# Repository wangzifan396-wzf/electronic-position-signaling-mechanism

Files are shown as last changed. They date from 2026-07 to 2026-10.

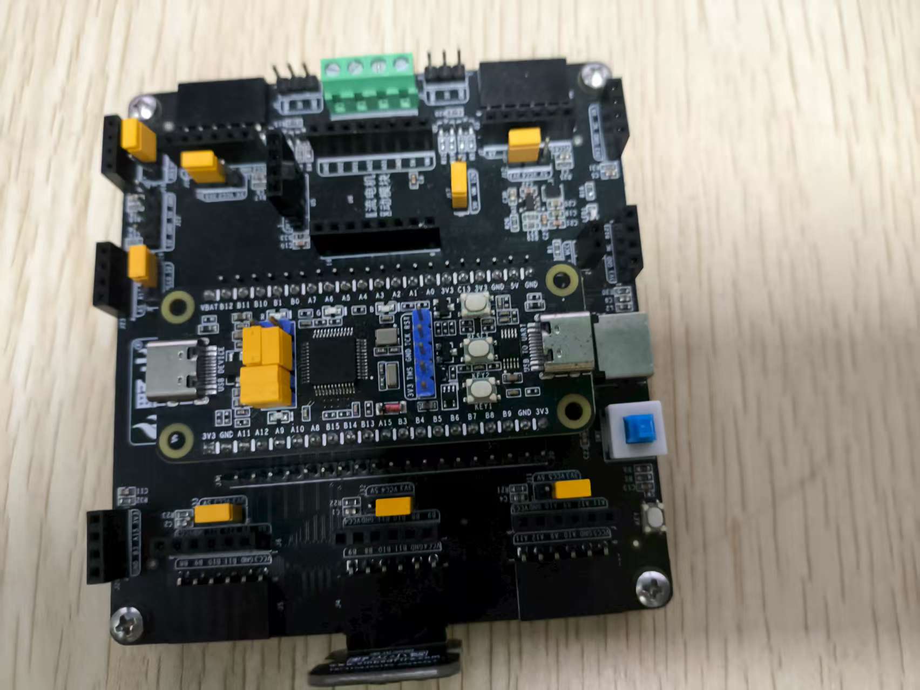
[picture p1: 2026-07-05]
[33]VL53L0X激光测距实验-3改/Doc/硬件接线图（含面包板+扩展板）/拓展板.jpg

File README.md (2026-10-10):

# Supporting research materials: electronic position-signaling mechanism

[中文说明](README.zh-CN.md) · [Final firmware release](https://github.com/wangzifan396-wzf/electronic-position-signaling-mechanism/releases/tag/v1.0.0) · [Manuscript correspondence and availability](docs/CODE_AVAILABILITY.md)

This repository provides firmware, mechanical models and engineering drawings accompanying a ground-based prototype study of an electronic position-signaling mechanism for coring. The implementation combines SDM18 distance sensing, stepper-driven inner-tube motion and ESP8266 TCP communication for position signaling, core-full and suspected-jamming alarms, and retrieval control.

**The main experiments reported in the manuscript used the single-attempt implementation (`wifi-once`).** Both author-designated final implementations are retained. Experimental procedures, actual parameter settings and reported results are documented in the manuscript; use its settings when reproducing a reported test.

## Materials

| Material | Entry point |
|---|---|
| Main experimental implementation | [firmware/wifi-once](firmware/wifi-once/) |
| Final implementation with failed-connection retries | [firmware/wifi-retry](firmware/wifi-retry/) |
| Mechanical models and original drawings | [Mechanical directory](%E6%9C%BA%E6%A2%B0/) · [Five drawing groups and thesis figures](%E6%9C%BA%E6%A2%B0/%E5%B7%A5%E7%A8%8B%E5%9B%BE/) |
| Original development projects | [Index of all 24 original directories](docs/PROJECT_FILES.md) |
| Citation and manuscript wording | [Code and design availability](docs/CODE_AVAILABILITY.md) |

The original directories and 16 mechanical models are retained in `main`. The drawing directory contains the original PDF/PNG exports, SolidWorks drawings and four engineering figures extracted unchanged from the thesis. The two final firmware implementations remain under `firmware/`.

## Firmware variants and experimental parameters

“Once” and “retry” refer to **WiFi connection attempts**. `wifi-once` attempts connection during startup; `wifi-retry` additionally retries at a nominal 30 s interval while the connection flag remains zero. These names do not indicate the number of coring cycles. [Implementation notes](docs/KNOWN_LIMITATIONS.md) explain the connection behavior in detail.

The two retained source snapshots contain initialization settings from different stages of the experimental work. The following values are **source defaults**; parameters for a reported experiment follow the corresponding manuscript record.

| Final source snapshot | Original final folder | Landed default | Upper/ground default | Core-full default |
|---|---|---:|---:|---:|
| [wifi-once](firmware/wifi-once/) | `SDM18测距机构-3wifi修改版（一次）` | 360 mm | 700 mm | 70 mm |
| [wifi-retry](firmware/wifi-retry/) | `SDM18测距机构-3wifi修改版（多次 ）` | 400 mm | 800 mm | 100 mm |

Landed, upper/ground, core-full and suspected-jamming thresholds, together with the motor software-delay setting, can be adjusted through TCP commands. `GET_PARAMS` returns the current settings. Changes are held in RAM; an MCU restart restores the source defaults. Timing and buffer settings are defined in the source and require recompilation to change. See the [command ranges and interface definitions](docs/PROTOCOL.md).

## Using the materials

1. For the main manuscript experiments, start with `firmware/wifi-once/` and configure the parameters reported for the relevant test.
2. Create the local network configuration from `Core/Inc/wifi_config.example.h`. Follow the [build and configuration guide](docs/BUILD.md) for the saved Keil project and board settings.
3. Use the drawing index to view full-sheet PDFs and locate the corresponding native CAD files. The PDFs can be read independently; opening native files may require locating their original model references.

[Source and build checks](docs/VALIDATION.md) document the checks performed for the published materials. [Implementation notes](docs/KNOWN_LIMITATIONS.md) retain the details needed to interpret and extend the original firmware.

## Cite and identify the materials

The fixed [v1.0.0 release](https://github.com/wangzifan396-wzf/electronic-position-signaling-mechanism/releases/tag/v1.0.0) identifies the two final firmware snapshots. Models and drawings are also available in the repository; the [availability guide](docs/CODE_AVAILABILITY.md) provides a fixed drawing snapshot and short Chinese/English manuscript statements. The existing v1.0.0 archives contain the firmware, while the engineering drawings added on 2026-10-10 are available separately in `main`.

`CITATION.cff` supplies the versioned software citation. The author's original code, self-drawn material and documentation use the [MIT license](LICENSE); third-party components retain their own licenses and notices. See [Third-party notices](THIRD_PARTY_NOTICES.md).

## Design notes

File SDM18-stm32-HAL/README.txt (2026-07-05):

/**********************************************************
***	Emm_V5.0步进闭环控制例程
***	控制例程：STM32_脉冲控制_while循环发送脉冲
***	编写作者：ZHANGDATOU
***	技术支持：张大头闭环伺服
***	淘宝店铺：https://zhangdatou.taobao.com
***	CSDN博客：http s://blog.csdn.net/zhangdatou666
***	qq交流群：262438510
**********************************************************/

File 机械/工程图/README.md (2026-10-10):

# Thesis engineering drawings / 论文工程图

[Mechanical directory / 返回机械目录](../) · [Repository guide / 仓库说明](../../README.md)

Added on **2026-10-10** from the author's original drawing set. The outer tube, rack, gear and inner-tube drawings correspond to the engineering views in thesis Figures 3-1 to 3-4. The simulated-core drawing is included from the same source set. The drawings and exported files are retained as supplied, without redrawing or changing dimensions.

2026-10-10新增作者原成套工程图。外管、齿条、齿轮、内管与论文终稿图3-1至图3-4中的工程视图对应，模拟岩芯为同套资料中的第五组图纸。原图及导出文件原样保留，没有重绘或改写尺寸。

## Five drawing groups / 五组工程图

PDF files contain the full original drawing sheet and title block. Use PDF to read dimensions, PNG for a quick preview, and SLDDRW to edit in SolidWorks.

PDF保留完整原图纸及题栏，建议用PDF查看尺寸、PNG快速浏览，需编辑时使用SolidWorks原工程图。

| Component / 部件 | PDF drawing / 完整图纸 | PNG preview / 预览 | SolidWorks original / 原工程图 | Thesis figure / 终稿图号 |
|---|---|---|---|---|
| Outer tube / 外管 | [PDF](PDF/90%E5%A4%96%E7%AE%A1.pdf) | [PNG](PNG/90%E5%A4%96%E7%AE%A1_01.png) | [SLDDRW](SolidWorks/90%E5%A4%96%E7%AE%A1.SLDDRW) | 图3-1 |
| Inner tube / 内管 | [PDF](PDF/65%E5%86%85%E7%AE%A1.pdf) | [PNG](PNG/65%E5%86%85%E7%AE%A1_01.png) | [SLDDRW](SolidWorks/65%E5%86%85%E7%AE%A1.SLDDRW) | 图3-4 |
| Rack / 齿条 | [PDF](PDF/%E9%BD%BF%E6%9D%A1.pdf) | [PNG](PNG/%E9%BD%BF%E6%9D%A1_01.png) | [SLDDRW](SolidWorks/%E9%BD%BF%E6%9D%A1.SLDDRW) | 图3-2 |
| Gear / 齿轮 | [PDF](PDF/%E9%BD%BF%E8%BD%AE.pdf) | [PNG](PNG/%E9%BD%BF%E8%BD%AE_01.png) | [SLDDRW](SolidWorks/%E9%BD%BF%E8%BD%AE.SLDDRW) | 图3-3 |
| Simulated core / 模拟岩芯 | [PDF](PDF/%E6%A8%A1%E6%8B%9F%E5%B2%A9%E8%8A%AF.pdf) | [PNG](PNG/%E6%A8%A1%E6%8B%9F%E5%B2%A9%E8%8A%AF_01.png) | [SLDDRW](SolidWorks/%E6%A8%A1%E6%8B%9F%E5%B2%A9%E8%8A%AF.SLDDRW) | — |

`SolidWorks/` contains **six native CAD files: five SLDDRW drawings and one SLDPRT rack model**. The same-source [rack model](SolidWorks/%E9%BD%BF%E6%9D%A1.SLDPRT) is kept next to its drawing. It differs from the original rack model in the parent mechanical directory and does not replace that file.

`SolidWorks/`共有**6个CAD原文件：5个SLDDRW工程图、1个SLDPRT齿条模型**。同源齿条模型与其工程图一同保存，与上级机械目录中的原齿条模型分别保留。

## Original thesis images / 论文原图

These four PNG files were extracted as the exact embedded image bytes from the thesis. They preserve the author's original combined engineering views and model screenshots. They are distinct from the full-sheet PNG exports above.

以下4幅PNG为论文中嵌入图片的原字节提取，保留作者原有的设计视图与模型截图组合；它们与上面的完整工程图PNG导出文件分别保存。

| Thesis figure / 论文图号 | Original image / 原图 | Corresponding drawing group / 对应工程图组 |
|---|---|---|
| 图3-1 | [论文原图 / Original image](%E8%AE%BA%E6%96%87%E5%8E%9F%E5%9B%BE/%E5%9B%BE3-1_%E5%A4%96%E7%AE%A1.png) | 90外管 |
| 图3-4 | [论文原图 / Original image](%E8%AE%BA%E6%96%87%E5%8E%9F%E5%9B%BE/%E5%9B%BE3-4_%E5%86%85%E7%AE%A1%E6%80%BB%E6%88%90.png) | 65内管 |
| 图3-2 | [论文原图 / Original image](%E8%AE%BA%E6%96%87%E5%8E%9F%E5%9B%BE/%E5%9B%BE3-2_%E9%BD%BF%E6%9D%A1.png) | 齿条 |
| 图3-3 | [论文原图 / Original image](%E8%AE%BA%E6%96%87%E5%8E%9F%E5%9B%BE/%E5%9B%BE3-3_%E9%BD%BF%E8%BD%AE.png) | 齿轮 |

## File integrity and opening CAD files / 文件校验与CAD打开说明

[DRAWING_MANIFEST.json](DRAWING_MANIFEST.json) records the relative path, size and SHA-256 of each of the **20 original files**: five PDFs, five PNG previews, five SLDDRW drawings, one SLDPRT rack model and four thesis images. The manifest and this guide are additional documentation, not part of that 20-file count.

清单记录20个原文件的路径、大小及SHA-256：5个PDF、5个PNG、5个SLDDRW、1个SLDPRT和4幅论文原图。校验清单与本说明属于另增文档，不计入20个原文件。

The native CAD files retain their original references. Their external dependencies have not been resolved or rebuilt in SolidWorks during this update. When opening a drawing, locate the referenced part or assembly if SolidWorks requests it; the PDFs can be viewed independently. Publication of these files is not a new manufacturing review or a validation of rebuilt CAD dependencies.

CAD原件保留原引用，本次未在SolidWorks中重新解析依赖或重建。打开图纸时，如软件提示缺少零件或装配体，请定位对应模型；PDF不依赖CAD模型即可查看。本次公开原图不代表新增制造校审或已验证CAD依赖完整。

The author's self-drawn material is covered by the repository's [MIT license](../../LICENSE). Third-party supplied models and vendor material retain their original terms; see [Third-party notices](../../THIRD_PARTY_NOTICES.md).

作者自绘资料采用根目录MIT许可；第三方随附模型与厂商资料继续遵循原许可，详见上述第三方说明。

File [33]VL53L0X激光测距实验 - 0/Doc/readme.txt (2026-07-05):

/*********************************************************************************************/
/*【*】程序简介

- 工程名称        ：VL53L0X 激光测距传感器实验
- 实验平台        ：野火 STM32F103C8T6-STM32开发板  

【 ！】功能简介：

本实验实现 VL53L0X 激光测距模块的初始化、周期性读取并通过串口打印测量距离值（单位：mm）

【 ！】实验操作：

    1. 编译并下载程序到开发板；
    2. 打开串口调试助手，观察 0.5s 周期输出的测距数据；
    3. 对传感器前方不同距离放置障碍物，可观察数据变化；
*/
/*********************************************************************************************/

/*【*】 引脚分配

NRST -> NRST              按键按下为低电平，核心板板载默认上拉且硬件有消抖

DEBUG_TX -> USART1_TXD -> PA9     PA9 作为 USART1 的 TXD，用于串口打印调试信息  
DEBUG_RX -> USART1_RXD -> PA10    PA10 作为 USART1 的 RXD，默认接收不使用

IIC_SCL -> PB10            PB10 作为硬件 I2C 的 SCL，引脚连接 VL53L0X 的 SCL
IIC_SDA -> PB11            PB11 作为硬件 I2C 的 SDA，引脚连接 VL53L0X 的 SDA

XSHUT  -> PB8             VL53L0X 的硬件复位引脚，用于模块地址配置或重新上电（可选连接）
INT    -> PB9             VL53L0X 的中断引脚（可选连接），用于新数据到达中断

*/
/*********************************************************************************************/

/*【*】程序描述：

< main.c >

    1. 初始化 USART1，用于打印测距数据；
    2. 初始化 I2C2，并配置 VL53L0X 相关寄存器；
    3. 使用 VL53L0X 驱动库完成传感器初始化与数据获取；
    4. 主循环中每隔 0.5 秒读取一次距离并打印到串口；
    5. 可扩展多个 VL53L0X 模块进行多点测距（需使用 XSHUT 引脚设置不同 I2C 地址）；
*/
/*********************************************************************************************/

【*】 联系我们

-野火官网  :https://embedfire.com
-野火论坛  :http://www.firebbs.cn
-野火商城  :https://yehuosm.tmall.com/
-野火资料下载中心：http://doc.embedfire.com/products/link

/*********************************************************************************************/

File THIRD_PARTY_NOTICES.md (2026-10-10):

# Third-party licenses and retained notices

The root `LICENSE` applies to the project author's original contributions and release documentation. It does not relicense generated/vendor code or remove any original copyright notice. Files with their own notice remain governed by that notice; original notices have been retained unchanged.

The following table describes the two curated projects under `firmware/` and the fixed `v1.0.0` release.

| Retained component | Applicable original license/notice | Included location in each variant |
|---|---|---|
| Arm CMSIS headers | Apache License 2.0 | `Drivers/CMSIS/LICENSE.txt`, `Drivers/CMSIS/Include/` |
| ST/Arm STM32F1 CMSIS Device | Apache License 2.0 as specified by its supplied license | `Drivers/CMSIS/Device/ST/STM32F1xx/LICENSE.txt` |
| ST STM32F1 HAL/LL driver | BSD-3-Clause when received without a package license, as specified by its supplied license | `Drivers/STM32F1xx_HAL_Driver/LICENSE.txt`; full BSD text also in `LICENSES/ST-BSD-3-Clause.txt` |
| ST generated configuration and startup scaffolding | Original file-level ST notices, including BSD terms where stated | `Core/`, `MDK-ARM/startup_stm32f103xe.s` |

The official [STM32CubeF1 component license table](https://github.com/STMicroelectronics/STM32CubeF1/blob/master/LICENSE.md) lists CMSIS and CMSIS Device under Apache-2.0 and STM32F1 HAL under BSD-3-Clause. The added full BSD text was retrieved from the [official HAL driver license](https://github.com/STMicroelectronics/stm32f1xx-hal-driver/blob/master/LICENSE.md); the original bundled license files are retained as well.

No additional author or license has been invented for helper files that contain no separate notice. The two curated `firmware/` projects and the fixed `v1.0.0` release omit toolchain executables, proprietary device packs, original binaries and personal debugger configuration. This omission statement does not describe the restored original project directories, which retain their originally uploaded contents.

## Restored original projects and mechanical material

On 2026-10-10, the original uploaded directories were restored from commit `5d6e080df02d82a73eb847e18485b2bdb33146d4`. Their files and original notices are preserved unchanged. These directories include earlier ST/Arm libraries, Wildfire (野火) example material, ZHANGDATOU-related driver/example material and VL53L0X platform files. Applicable terms must be read from each component's supplied license or file-level notice; some VL53L0X platform headers contain separate or proprietary terms. Restoration does not convert these materials to MIT or supply a missing third-party permission.

The MIT license applies to the project author's own code, self-drawn figures and documentation. Supplied third-party models, hardware examples and vendor materials retain their respective terms. A filename or inclusion in this repository does not establish authorship or change the original license.

中文说明：MIT只覆盖本项目作者的原创贡献（包括原创代码、自绘图纸）和发布文档；自动生成、厂商及其他第三方文件保留原版权、原许可证。`firmware/`规范工程中排除旧编译产物、个人调试配置等，不代表原样恢复的旧目录也排除了这些内容。旧目录中的ST/Arm、野火、ZHANGDATOU相关资料及VL53L0X平台文件按各自原许可或文件头声明使用，不能将整个旧目录概括为MIT。第三方随附模型亦不因本次恢复而被重新授权。

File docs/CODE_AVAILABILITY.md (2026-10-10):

# Manuscript correspondence and material availability / 论文对应关系与资料可用性

[Repository guide / 仓库说明](../README.md) · [中文说明](../README.zh-CN.md) · [Drawings / 工程图](../%E6%9C%BA%E6%A2%B0/%E5%B7%A5%E7%A8%8B%E5%9B%BE/)

The repository supplies code and mechanical design files accompanying the study. The manuscript describes the mechanism, experimental procedures, actual settings and reported results. The paragraphs below can be used in a code/design-availability section or a short appendix.

本仓库提供研究配套的代码与机械设计文件，机构原理、试验方法、实际设置和结果由论文阐述。以下简短表述可用于“代码与设计文件可用性”部分或附录。

## Relationship to the manuscript / 与论文的对应关系

The author has confirmed that the **main experiments reported in the manuscript used the single-attempt implementation**, provided as [wifi-once](../firmware/wifi-once/). [wifi-retry](../firmware/wifi-retry/) is retained as the other final implementation. Both source snapshots retain initialization parameters from different stages of the experimental work. For an individual reported test, use the settings stated in the manuscript and its corresponding record.

经作者确认，**论文主要试验采用“一次”版实现**，对应`wifi-once`；`wifi-retry`作为另一份最终实现保留。两份源码保留了不同时期试验的初始化设置。复现某项试验时，按论文及该试验记录设置参数。

The version names describe WiFi connection attempts. `wifi-once` attempts connection at startup; `wifi-retry` adds retries while the connection flag remains zero. The source-default landed/upper/core-full thresholds are 360/700/70 mm and 400/800/100 mm, respectively. These defaults identify the snapshots; the manuscript supplies the parameters of its reported experiments.

版本名称指WiFi建连尝试方式。一次版在启动时尝试连接，多次版在连接标志为0时继续尝试。两份源码到位/地面/满心初始化阈值分别为360/700/70 mm和400/800/100 mm。默认值用于说明所保留源码的设置，论文具体试验采用文中报告的参数。

Five parameters can be adjusted through runtime TCP commands: landed, upper/ground, core-full and suspected-jamming range thresholds, and the motor software-delay setting. Changes reside in RAM; restarting the MCU restores source defaults. The motor setting is a software-delay value, rather than a calibrated rpm value. Waiting times, buffer length and connection-retry timing are source constants. See [command names, ranges and state output](PROTOCOL.md).

到位、地面、满心、卡心极差阈值及电机软件延时参数可通过运行时TCP指令修改；修改值保存在RAM中，MCU重启后恢复源码默认值。电机参数表示软件延时，不能直接作为标定转速。等待时间、缓存长度及建连重试间隔为源码常量。指令名称、范围和状态报文见通信协议。

## Fixed material references / 固定资料版本

| Material / 资料 | Fixed reference / 固定引用 |
|---|---|
| Both final firmware snapshots / 两份最终固件 | [v1.0.0 source release](https://github.com/wangzifan396-wzf/electronic-position-signaling-mechanism/releases/tag/v1.0.0) |
| Original models / 原机械模型 | [Mechanical snapshot, 2026-10-10](https://github.com/wangzifan396-wzf/electronic-position-signaling-mechanism/tree/c0c7b40e8158e27fce74b14fde9e506d6e431814/%E6%9C%BA%E6%A2%B0) |
| Engineering drawings and original thesis figures / 工程图及论文原图 | [Drawing snapshot, 2026-10-10](https://github.com/wangzifan396-wzf/electronic-position-signaling-mechanism/tree/c0c7b40e8158e27fce74b14fde9e506d6e431814/%E6%9C%BA%E6%A2%B0/%E5%B7%A5%E7%A8%8B%E5%9B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) |

The firmware release contains project files, required retained libraries, example network configuration and interface documentation. The mechanical snapshot contains the original 16 models and the added drawing set. The drawing set includes five PDFs, five PNG exports, five SolidWorks drawings, a same-source rack model and four original thesis images; [DRAWING_MANIFEST.json](../%E6%9C%BA%E6%A2%B0/%E5%B7%A5%E7%A8%8B%E5%9B%BE/DRAWING_MANIFEST.json) records their SHA-256 values. The pre-existing v1.0.0 firmware archives remain unchanged and do not contain the subsequently added mechanical drawing files.

固件发布版提供工程文件、保留的所需库、网络配置示例及接口说明。机械快照包含16个原模型和新增图纸集；图纸集包括5个PDF、5个PNG导出图、5个SolidWorks工程图、同源齿条模型及4幅论文原图，校验清单记录SHA-256。既有v1.0.0固件压缩包保持原样，后续补充的机械图纸通过上面的固定快照另行引用。

## 中文可用性表述

本研究配套的STM32控制与电子报信固件、机械模型及工程图已公开于[GitHub仓库](https://github.com/wangzifan396-wzf/electronic-position-signaling-mechanism)。论文主要试验采用启动时单次WiFi连接的实现（`wifi-once`）；采用失败建连重试策略的另一份最终实现（`wifi-retry`）亦予保留。两份固件的固定发布版本为[v1.0.0](https://github.com/wangzifan396-wzf/electronic-position-signaling-mechanism/releases/tag/v1.0.0)，机械模型与工程图见[2026-10-10固定快照](https://github.com/wangzifan396-wzf/electronic-position-signaling-mechanism/tree/c0c7b40e8158e27fce74b14fde9e506d6e431814/%E6%9C%BA%E6%A2%B0)。源码初始化值保留了不同时期的试验设置，本文报告试验的实际参数以文中记录为准。作者原创代码、自绘资料及文档采用MIT许可证，第三方资料保留原许可与声明。

## English availability statement

The STM32 control and electronic-signaling firmware, mechanical models and engineering drawings supporting this study are available in the [GitHub repository](https://github.com/wangzifan396-wzf/electronic-position-signaling-mechanism). The main experiments reported in the manuscript used the implementation that makes a single WiFi connection attempt at startup (`wifi-once`); the other final implementation, with failed-connection retries (`wifi-retry`), is also retained. Both firmware snapshots are identified by the fixed [v1.0.0 release](https://github.com/wangzifan396-wzf/electronic-position-signaling-mechanism/releases/tag/v1.0.0), and the mechanical models and drawings by the [2026-10-10 snapshot](https://github.com/wangzifan396-wzf/electronic-position-signaling-mechanism/tree/c0c7b40e8158e27fce74b14fde9e506d6e431814/%E6%9C%BA%E6%A2%B0). Source initialization values retain settings from different stages of the experimental work; the actual parameters of the reported tests are those recorded in the manuscript. The author's original code, self-drawn material and documentation are licensed under MIT; third-party material retains its original terms and notices.

## Suggested software reference / 固件参考文献

Wang, Z. (2026). Electronic position signaling and inner-tube control firmware (Version 1.0.0) [Computer software]. GitHub. https://github.com/wangzifan396-wzf/electronic-position-signaling-mechanism/releases/tag/v1.0.0

`CITATION.cff` describes this fixed software release. The separate mechanical snapshot can be identified by its commit and link in the availability statement. No software DOI or published-paper bibliographic details have been assigned in this repository.

`CITATION.cff`描述固定固件版本；机械资料在可用性声明中以提交快照及链接标识。仓库未填写软件DOI或尚未确定的已发表论文信息。

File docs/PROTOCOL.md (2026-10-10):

# Interfaces and text protocol / 接口与文本协议

These assignments and behaviors are read from the retained final sources in [wifi-once](../firmware/wifi-once) and [wifi-retry](../firmware/wifi-retry). They describe the code, not a new electrical or hardware verification. Both variants use the same pin assignments and command set.

## Pin assignments / 接口引脚

| Function / 功能 | STM32 pins / 引脚 | Source setting / 源码设置 |
|---|---|---|
| SDM18 ranging / 测距 | PA2 TX, PA3 RX | USART2, 921600 baud, 8N1 |
| Debug output / 调试输出 | PA9 TX, PA10 RX | USART1, 115200 baud, 8N1; `printf` output |
| ESP8266 AT interface | PB10 TX, PB11 RX | USART3, 115200 baud, 8N1 |
| ESP8266 reset / 复位 | PB9 | Driven low for 100 ms, then high; 2000 ms wait |
| WiFi IO | PB8 | Input with no pull-up/pull-down in the source |
| Stepper enable / 步进使能 | PA5 | EN, set high at initialization |
| Stepper pulse / 步进脉冲 | PA6 | STP, software-generated pin toggles |
| Stepper direction / 步进方向 | PA7 | DIR; high for lowering, low for retrieval |
| SWD programming | PA13, PA14 | SWDIO, SWCLK as recorded in the IOC |

UART TX connects to the other device's RX and vice versa, with a common reference ground. Supply voltages, electrical compatibility, driver enable polarity and mechanical direction must be checked against the actual hardware. No stepper-driver brand is prescribed by these pin definitions. The saved TIM3 setup is not the active pulse-generation method: the final code configures PA6 as a GPIO and toggles it in software.

串口TX/RX交叉连接并共地。实际供电、电平、驱动使能有效电平和机械运动方向需要按实物核对。上述引脚定义不指定步进驱动品牌，也不能把软件延时参数直接解释为电机转速。

## Connection / 网络角色

The ESP8266 is configured as a WiFi station and connects to the TCP server defined in the local `wifi_config.h`. It uses AT commands and transparent TCP transmission. The STM32 firmware is a TCP **client**, not a web server. The original host application is not part of these two source snapshots.

`wifi-once` attempts connection during startup. `wifi-retry` also attempts startup connection and checks for another attempt at a nominal 30 s interval while `wifi_connected` is zero. It does not implement complete detection and recovery of every disconnection after a successful connection; see [Known limitations](KNOWN_LIMITATIONS.md).

ESP8266以STA方式接入现有WiFi，并主动连接本地配置的TCP服务器。两版都不是网页服务端；重试版的重试条件是连接标志为0，不能等同于完整断线恢复。

## Experimental settings / 试验参数口径

The author confirms that the main experiments reported in the manuscript primarily used the single-attempt implementation, [wifi-once](../firmware/wifi-once). [wifi-retry](../firmware/wifi-retry) is retained as an alternative final source snapshot from another stage of the experimental work. The two snapshots retain their respective startup defaults; configure the settings reported in the manuscript when reproducing a particular experiment.

作者确认，论文报告的主要试验以[一次连接版](../firmware/wifi-once)为主；[重试连接版](../firmware/wifi-retry)作为另一实验阶段保留的最终源码一并公开。两份源码保留各自的初始化默认值，复现具体试验时按论文报告的参数配置。

Five settings can be changed through the commands below: the landed, upper/ground, core-full and suspected-jamming range thresholds, and the motor software-delay setting. These changes are stored in RAM; restarting the MCU restores the defaults defined in the selected source. The distance-buffer length, nominal control interval, landed/alarm pauses and WiFi retry interval are compile-time constants rather than remote command settings.

下述指令支持运行时修改五项参数：到位阈值、地面/上提阈值、满心阈值、卡心极差阈值和电机软件延时参数。修改值保存在 RAM 中，MCU 重启后恢复所选源码的默认值。距离缓存长度、名义控制间隔、到位与报警暂停时间，以及 WiFi 重试间隔属于编译期常量；修改这些设置需要修改源码并重新编译。

## Commands / 指令

Send raw ASCII command text, one command per line, terminated by LF or CRLF. Do not wrap it in JSON or add a prefix. CR is ignored and LF completes a command. Commands longer than 100 characters are ignored. Send one command and wait for its response before sending another; the implementation has no command queue.

| Command | Value or action / 参数与行为 |
|---|---|
| `SET_IN_PLACE\|N` | Landed threshold / 到位阈值: 100–1000 mm |
| `SET_GROUND\|N` | Upper/ground threshold / 地面阈值: 500–1500 mm |
| `SET_FULL\|N` | Core-full threshold / 满心阈值: 20–200 mm |
| `SET_STUCK\|N` | Suspected-jamming range / 卡心极差阈值: 1–50 mm |
| `SET_SPEED\|N` | Software delay setting / 软件延时参数: 100–5000, not rpm |
| `GET_PARAMS` | Return current RAM parameters / 返回当前RAM参数 |
| `CMD_DOWN` | Enter manual lowering / 手动下放 |
| `CMD_UP` | Enter manual retrieval / 手动上提 |
| `CMD_STOP` | Request manual stop / 请求手动停止 |
| `CMD_RESET` | Clear movement state and return to automatic mode / 清运动状态并恢复自动模式 |

For example, send `GET_PARAMS` followed by a newline to query settings. Setter values are retained only in RAM. `CMD_RESET` is not an MCU reboot and does not restore default thresholds. Manual movement bypasses the automatic distance-limit path; `CMD_STOP` is a firmware command, not a verified hardware emergency-stop circuit.

参数修改只作用于RAM。`CMD_RESET`不重启MCU、不恢复默认阈值；手动运动不经过自动限位路径。源码中的“急停”命令不能作为硬件安全急停验证。

## State output / 状态报文

The periodic status line has this field order:

```text
DATA|uptime_s|distance_mm|mode|status|in_place|reversing|avg_mm|range_mm|in_place_threshold_mm|ground_threshold_mm|speed_setting
```

| Field | Meaning / 含义 |
|---|---|
| `uptime_s` | `HAL_GetTick()/1000`; elapsed MCU time, not a date/time |
| `distance_mm` | Current cached distance / 当前缓存距离 |
| `mode` | `IDLE`, `DOWN`, `UP`, or `PAUSE` |
| `status` | `IN_PLACE`, `REVERSING`, `DRILLING`, `WAITING`, `PAUSING`, or `NORMAL` |
| `in_place`, `reversing` | State flags / 到位与上提状态标志 |
| `avg_mm` | Integer mean after the buffer fills; otherwise 0 / 缓存充满后为整数均值，否则为0 |
| `range_mm` | Range of all 10 entries, including initial zero entries until filled / 始终计算10项数组极差，未充满时包含初始零值 |
| Last three fields | Current landed/upper thresholds and speed setting / 当前到位、地面阈值及速度设置 |

The parameter response uses:

```text
PARAMS|IN_PLACE=...|GROUND=...|FULL=...|STUCK=...|SPEED=...
```

Additional `OK`, state and alarm messages are emitted, so a host must not assume every line is a `DATA` record. Some final-source message calls use fixed lengths that exceed their literal text length; original behavior is retained and documented in [Known limitations](KNOWN_LIMITATIONS.md).

## Automatic control / 自动流程

The final implementation lowers in the interval between the landed and upper thresholds, stops at the landed threshold, waits 5 s on first landing, and then evaluates core-full followed by suspected-jamming conditions. An alarm triggers a 3 s pause before retrieval to the upper threshold. A zero distance returns early from the control function, and reaching the upper threshold does not automatically start another cycle. Exact execution order is in `Drill_Control`, `Check_Full` and `Check_Stuck` in each variant's `Core/Src/main.c`.

自动路径在到位与地面阈值之间下放，首次到位后等待5 s，再按满心优先、卡心其次的顺序判断；报警后暂停3 s再上提。距离为0时本次控制提前返回，上提结束不自动开始下一轮。阈值条件及顺序以相应版本源码为准。

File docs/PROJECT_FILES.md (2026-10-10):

# Original project directories / 原项目目录索引

[Repository guide / 仓库说明](../README.md) · [中文说明](../README.zh-CN.md) · [Mechanical drawings / 机械工程图](../%E6%9C%BA%E6%A2%B0/%E5%B7%A5%E7%A8%8B%E5%9B%BE/)

All 24 original root directories were restored on 2026-10-10 from [commit `5d6e080`](https://github.com/wangzifan396-wzf/electronic-position-signaling-mechanism/tree/5d6e080df02d82a73eb847e18485b2bdb33146d4). Their original files are unchanged. The mechanical directory also contains the newly added drawing subdirectory and guide. The links below open the current folders, rather than requiring a reader to search old commits.

2026-10-10已从上述原提交将全部24个原目录恢复到当前分支，原有文件原样保留；机械目录另新增工程图子目录及说明。以下链接直接进入当前目录。

The latest curated final firmware remains [wifi-once](../firmware/wifi-once/) and [wifi-retry](../firmware/wifi-retry/), with the fixed [v1.0.0 release](https://github.com/wangzifan396-wzf/electronic-position-signaling-mechanism/releases/tag/v1.0.0). The original final-version folders listed here remain their original uploaded snapshots. Version names are preserved; this index does not infer chronology or validated performance from those names.

两份规范整理的最终固件仍为上面的`wifi-once`和`wifi-retry`。下表中的原最终版本目录作为未经重新整理的上传快照保留，不与固定发布目录混同，也不凭文件名推定试验结论或版本先后。

| No. | Original directory / 原目录（当前可访问） |
|---:|---|
| 1 | [`SDM18-stm32-HAL - 副本`](../SDM18-stm32-HAL%20-%20%E5%89%AF%E6%9C%AC/) |
| 2 | [`SDM18-stm32-HAL-1 - 副本`](../SDM18-stm32-HAL-1%20-%20%E5%89%AF%E6%9C%AC/) |
| 3 | [`SDM18-stm32-HAL`](../SDM18-stm32-HAL/) |
| 4 | [`SDM18测距机构 - 副本`](../SDM18%E6%B5%8B%E8%B7%9D%E6%9C%BA%E6%9E%84%20-%20%E5%89%AF%E6%9C%AC/) |
| 5 | [`SDM18测距机构-1 - 副本`](../SDM18%E6%B5%8B%E8%B7%9D%E6%9C%BA%E6%9E%84-1%20-%20%E5%89%AF%E6%9C%AC/) |
| 6 | [`SDM18测距机构-1`](../SDM18%E6%B5%8B%E8%B7%9D%E6%9C%BA%E6%9E%84-1/) |
| 7 | [`SDM18测距机构-2 - 副本`](../SDM18%E6%B5%8B%E8%B7%9D%E6%9C%BA%E6%9E%84-2%20-%20%E5%89%AF%E6%9C%AC/) |
| 8 | [`SDM18测距机构-2.1 - 副本`](../SDM18%E6%B5%8B%E8%B7%9D%E6%9C%BA%E6%9E%84-2.1%20-%20%E5%89%AF%E6%9C%AC/) |
| 9 | [`SDM18测距机构-2.1`](../SDM18%E6%B5%8B%E8%B7%9D%E6%9C%BA%E6%9E%84-2.1/) |
| 10 | [`SDM18测距机构-3 - 副本`](../SDM18%E6%B5%8B%E8%B7%9D%E6%9C%BA%E6%9E%84-3%20-%20%E5%89%AF%E6%9C%AC/) |
| 11 | [`SDM18测距机构-3wifi修改版（一次）`](../SDM18%E6%B5%8B%E8%B7%9D%E6%9C%BA%E6%9E%84-3wifi%E4%BF%AE%E6%94%B9%E7%89%88%EF%BC%88%E4%B8%80%E6%AC%A1%EF%BC%89/) |
| 12 | [`SDM18测距机构-3wifi修改版（多次 ）`](../SDM18%E6%B5%8B%E8%B7%9D%E6%9C%BA%E6%9E%84-3wifi%E4%BF%AE%E6%94%B9%E7%89%88%EF%BC%88%E5%A4%9A%E6%AC%A1%20%EF%BC%89/) |
| 13 | [`SDM18测距机构-wifi网页修改版`](../SDM18%E6%B5%8B%E8%B7%9D%E6%9C%BA%E6%9E%84-wifi%E7%BD%91%E9%A1%B5%E4%BF%AE%E6%94%B9%E7%89%88/) |
| 14 | [`STM32_脉冲控制_while循环发脉冲-1`](../STM32_%E8%84%89%E5%86%B2%E6%8E%A7%E5%88%B6_while%E5%BE%AA%E7%8E%AF%E5%8F%91%E8%84%89%E5%86%B2-1/) |
| 15 | [`STM32_脉冲控制_while循环发脉冲`](../STM32_%E8%84%89%E5%86%B2%E6%8E%A7%E5%88%B6_while%E5%BE%AA%E7%8E%AF%E5%8F%91%E8%84%89%E5%86%B2/) |
| 16 | [`[33]VL53L0X激光测距实验 - 0`](../%5B33%5DVL53L0X%E6%BF%80%E5%85%89%E6%B5%8B%E8%B7%9D%E5%AE%9E%E9%AA%8C%20-%200/) |
| 17 | [`[33]VL53L0X激光测距实验-1`](../%5B33%5DVL53L0X%E6%BF%80%E5%85%89%E6%B5%8B%E8%B7%9D%E5%AE%9E%E9%AA%8C-1/) |
| 18 | [`[33]VL53L0X激光测距实验-2`](../%5B33%5DVL53L0X%E6%BF%80%E5%85%89%E6%B5%8B%E8%B7%9D%E5%AE%9E%E9%AA%8C-2/) |
| 19 | [`[33]VL53L0X激光测距实验-3改`](../%5B33%5DVL53L0X%E6%BF%80%E5%85%89%E6%B5%8B%E8%B7%9D%E5%AE%9E%E9%AA%8C-3%E6%94%B9/) |
| 20 | [`[33]VL53L0X激光测距实验-4`](../%5B33%5DVL53L0X%E6%BF%80%E5%85%89%E6%B5%8B%E8%B7%9D%E5%AE%9E%E9%AA%8C-4/) |
| 21 | [`[33]VL53L0X激光测距实验-5 - 副本`](../%5B33%5DVL53L0X%E6%BF%80%E5%85%89%E6%B5%8B%E8%B7%9D%E5%AE%9E%E9%AA%8C-5%20-%20%E5%89%AF%E6%9C%AC/) |
| 22 | [`[33]VL53L0X激光测距实验-测试`](../%5B33%5DVL53L0X%E6%BF%80%E5%85%89%E6%B5%8B%E8%B7%9D%E5%AE%9E%E9%AA%8C-%E6%B5%8B%E8%AF%95/) |
| 23 | [`机械`](../%E6%9C%BA%E6%A2%B0/) |
| 24 | [`老转新`](../%E8%80%81%E8%BD%AC%E6%96%B0/) |

The original directories retain their original library packages, build outputs and settings when these were part of the original upload. They may contain old network configuration that the owner has confirmed is no longer used. File-level and component-level licenses remain applicable; the root MIT license does not relicense third-party files.

原上传目录中原有的库包、编译产物及设置也予以保留，可能含作者确认已不再使用的旧网络配置。各组件及文件的原许可证继续适用，根目录MIT不替代第三方许可。详见[第三方说明](../THIRD_PARTY_NOTICES.md)。

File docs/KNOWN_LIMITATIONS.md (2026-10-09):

# Implementation notes / 已知实现限制

This release preserves the author-designated final control implementation. These observations come from source inspection, not additional hardware or network experiments. They are documented so that users can reproduce the snapshot and identify what needs validation before extending it. Fixes should be published under a separately identified version rather than silently altering this research snapshot.

本发布保留最终控制实现。以下说明来自源码核对，不是新增实物或网络测试结果；用于解释复现边界。后续修复应另列版本，避免改变已有研究快照。

The relevant implementations are in [wifi-once/main.c](../firmware/wifi-once/Core/Src/main.c), [wifi-retry/main.c](../firmware/wifi-retry/Core/Src/main.c), and each variant's `HARDWARE/SMD18.c`.

| Topic | Actual implementation and implication / 实际实现与含义 |
|---|---|
| Connection retries / 连接重试 | Retry is conditioned on a zero connection flag. There is no complete handling of `CLOSED` notifications or resetting the flag after every send failure. It is failed-connection retry, not guaranteed recovery after any disconnect. / 按连接标志进行失败建连重试，未实现任意断线后的完整恢复。 |
| Timing and buffer / 时序与缓存 | The main loop reads a shared distance cache at a nominal 100 ms interval. AT waits, serial output and the 5 s landed delay can block it. Ten entries do not establish ten independent sensor updates or a fixed 1 s response bound. / 10项为控制程序读取的缓存，不能据此推出独立采样次数或固定响应时间。 |
| Manual movement / 手动运动 | The manual path returns before automatic limit checks. It does not inherit automatic upper/landed stopping protection. / 手动路径绕过自动距离限位。 |
| Zero distance and stopping / 零读数与停止 | A zero distance returns before the manual-control branch, without explicitly stopping the existing motor state. This can delay applying a stop command. / 零读数提前返回，未主动停止原电机状态，也可能延迟停止指令执行。 |
| Transmission lengths / 发送长度 | Several fixed `WiFi_SendData` lengths exceed their string literal payloads. For example, `OK\|IN_PLACE_CHANGED\r\n` is 21 ASCII bytes, but the code passes 23. This can transmit a NUL and, in some calls, read beyond the literal. / 部分固定发送长度超出字符串长度，可能带出NUL或越界字节。 |
| Command buffering / 命令缓存 | The UART interrupt reuses a buffer after setting the command-ready flag; there is no queue or atomic snapshot. Rapid commands can overwrite pending text. Parsing uses `atoi` and does not fully validate integer syntax or relationships among thresholds. / 无命令队列和原子快照，连续指令可能覆盖待处理内容。 |
| Sensor frame bounds / 传感器报文边界 | The 30-byte decoder buffer is indexed using a received length without first checking a valid maximum. CRC validation alone does not protect the preceding indexing path from an abnormal frame. / 缓冲区长度30字节，未先限制报文长度；异常报文可能导致越界。 |
| Pulse speed / 脉冲速度 | PA6 is toggled in the main loop after a delay loop. Timing depends on loop/communication load; the speed setting is not calibrated rpm, and the toggle count is not a measured displacement. / 软件翻转受主循环负载影响，延时参数不是标定转速。 |
| Persistence and access / 持久化与访问 | Parameters are in RAM; there is no saved-parameter path, TLS or command authentication in these files. / 参数不持久保存，当前文件未实现TLS和指令鉴权。 |
| Original project settings / 原工程设置 | RC/xE device/startup records coexist with legacy C8 Flash/SVD references and historical memory regions. Build/download settings must be checked for the actual MCU. / RC/xE记录与C8遗留配置并存，需按实物核对。 |
| Character encoding / 字符编码 | Rebuilding with the saved ARMCC version reports multibyte warnings for Chinese/Unicode `printf` literals, plus missing-final-newline warnings. Actual serial rendering has not been newly tested. / 原工具链对中文、Unicode输出字符串和末尾换行产生警告，未重新验证串口字符显示。 |

No new sensor accuracy, classification accuracy, drilling performance, field reliability or space-qualification result is inferred from this source release.

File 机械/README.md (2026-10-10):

# Mechanical models and drawings / 机械模型与工程图

[Repository guide / 仓库说明](../README.md) · [Drawing index / 工程图索引](%E5%B7%A5%E7%A8%8B%E5%9B%BE/) · [Original project index / 原项目索引](../docs/PROJECT_FILES.md)

The 16 original SolidWorks assembly/part files in this directory were restored unchanged from the original uploaded commit. The new `工程图/` subdirectory contains the author's engineering drawings corresponding to the thesis, as original PDF, PNG and SolidWorks files, together with the original thesis images and a hash manifest.

本目录的16个原SolidWorks装配体、零件文件已从原上传提交原样恢复。新增`工程图/`子目录保留论文终稿对应的原PDF、PNG、SolidWorks工程图，以及论文原图和文件校验清单。

## Drawings / 工程图

[Open the five drawing groups and thesis-figure mapping / 查看五组工程图及论文原图对应关系](%E5%B7%A5%E7%A8%8B%E5%9B%BE/)。PDF可独立查看尺寸；PNG用于快速浏览；SolidWorks原件用于后续编辑。

## Original models / 原模型文件

| Original file / 原文件 |
|---|
| [`28smd18.SLDASM`](28smd18.SLDASM) |
| [`65外管.SLDPRT`](65%E5%A4%96%E7%AE%A1.SLDPRT) |
| [`80外管.SLDPRT`](80%E5%A4%96%E7%AE%A1.SLDPRT) |
| [`HPB28-L1-(A)-S2-P2-（5-10-22-2.8-F23）.SLDASM`](HPB28-L1-%28A%29-S2-P2-%EF%BC%885-10-22-2.8-F23%EF%BC%89.SLDASM) |
| [`SDM18（含外壳）.SLDASM`](SDM18%EF%BC%88%E5%90%AB%E5%A4%96%E5%A3%B3%EF%BC%89.SLDASM) |
| [`TB6612双路驱动稳压模块（D153C).SLDPRT`](TB6612%E5%8F%8C%E8%B7%AF%E9%A9%B1%E5%8A%A8%E7%A8%B3%E5%8E%8B%E6%A8%A1%E5%9D%97%EF%BC%88D153C%29.SLDPRT) |
| [`c8t6.SLDPRT`](c8t6.SLDPRT) |
| [`widi.SLDPRT`](widi.SLDPRT) |
| [`三角电池.SLDPRT`](%E4%B8%89%E8%A7%92%E7%94%B5%E6%B1%A0.SLDPRT) |
| [`岩芯.SLDPRT`](%E5%B2%A9%E8%8A%AF.SLDPRT) |
| [`支撑盖板.SLDPRT`](%E6%94%AF%E6%92%91%E7%9B%96%E6%9D%BF.SLDPRT) |
| [`满岩芯.SLDPRT`](%E6%BB%A1%E5%B2%A9%E8%8A%AF.SLDPRT) |
| [`盖板上.SLDPRT`](%E7%9B%96%E6%9D%BF%E4%B8%8A.SLDPRT) |
| [`盖板下.SLDPRT`](%E7%9B%96%E6%9D%BF%E4%B8%8B.SLDPRT) |
| [`齿条.SLDPRT`](%E9%BD%BF%E6%9D%A1.SLDPRT) |
| [`齿轮.SLDPRT`](%E9%BD%BF%E8%BD%AE.SLDPRT) |

These models preserve the original upload. The added `工程图/SolidWorks/齿条.SLDPRT` is the model supplied with the selected drawing set and differs from the original `齿条.SLDPRT` in this directory; both are retained without overwriting either file.

新增`工程图/SolidWorks/齿条.SLDPRT`来自所选成套工程图，与本目录原`齿条.SLDPRT`为不同文件，两者分别保留，未覆盖原模型。

The SolidWorks files retain their original references. They have not been reopened or rebuilt in SolidWorks for this publication update; opening an assembly or drawing may require locating its referenced models. See the drawing guide for the retained source set.

SolidWorks文件保留原引用，本次未在SolidWorks中重新打开或重建；打开装配体或图纸时，可能需要手动定位所引用模型。作者原创资料采用[MIT](../LICENSE)，第三方随附模型及厂商资料保留原许可，详见[第三方说明](../THIRD_PARTY_NOTICES.md)。

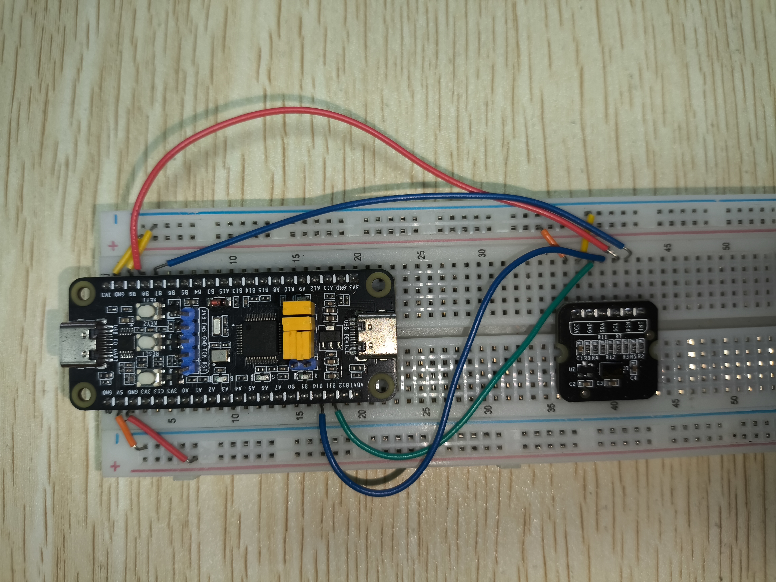
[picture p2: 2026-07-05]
[33]VL53L0X激光测距实验-5 - 副本/Doc/硬件接线图（含面包板+扩展板）/面包板.jpg

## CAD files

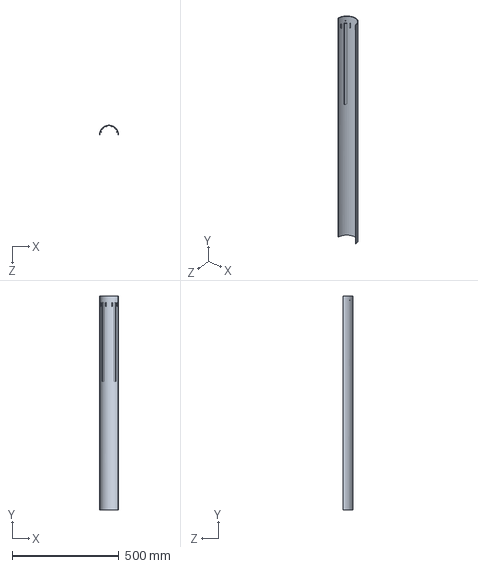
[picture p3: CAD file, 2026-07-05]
机械/80外管.SLDPRT
90.0 x 1000.0 x 44.8 mm

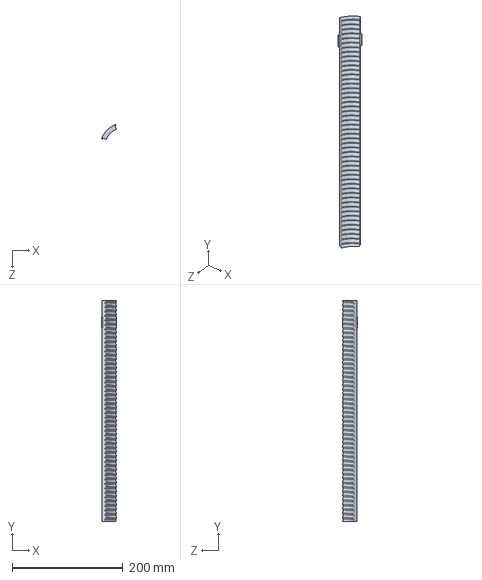
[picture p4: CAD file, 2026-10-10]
机械/工程图/SolidWorks/齿条.SLDPRT
27.0 x 400.0 x 27.0 mm

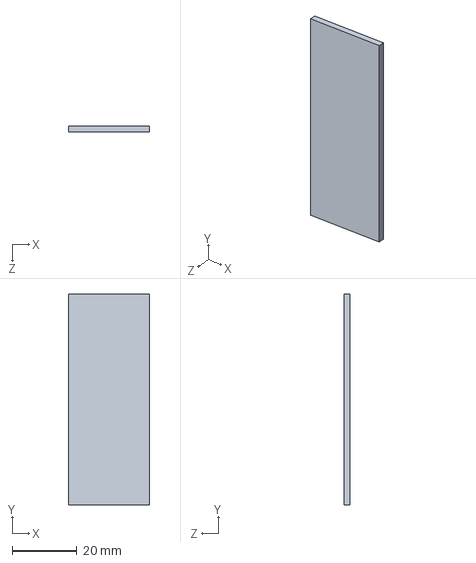
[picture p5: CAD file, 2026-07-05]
机械/c8t6.SLDPRT
25.0 x 65.0 x 2.00 mm

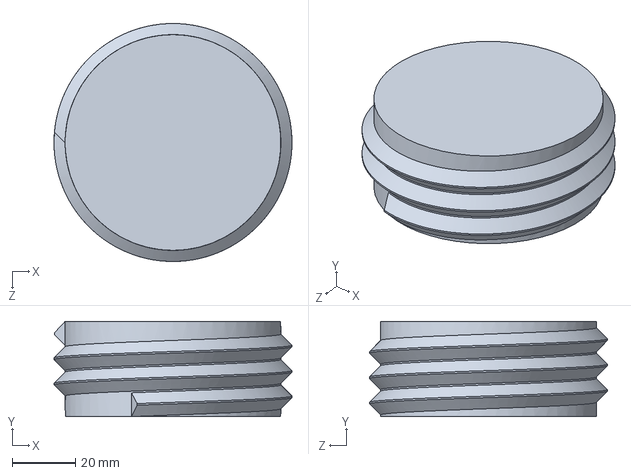
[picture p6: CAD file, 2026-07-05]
机械/齿轮.SLDPRT
75.0 x 30.0 x 75.0 mm

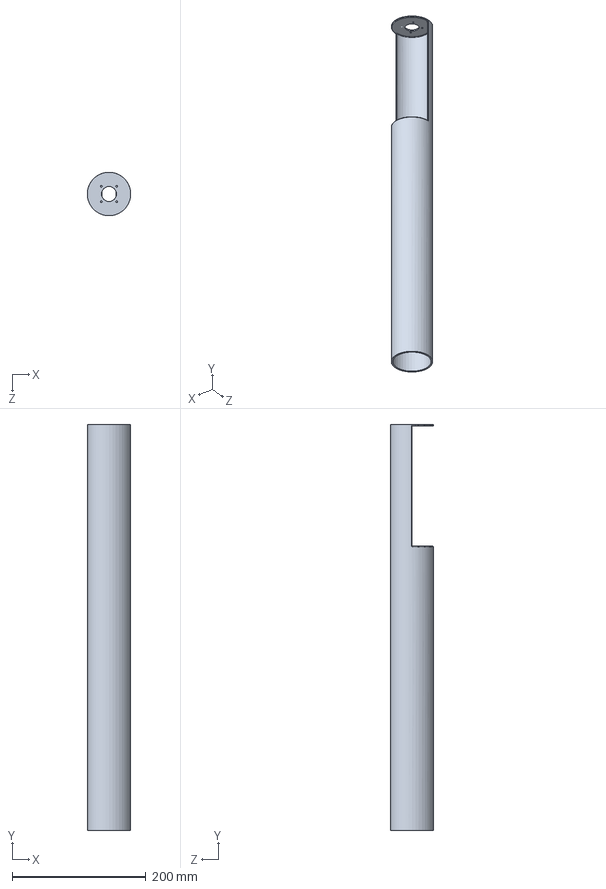
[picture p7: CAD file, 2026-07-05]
机械/65外管.SLDPRT
65.0 x 607.0 x 65.0 mm

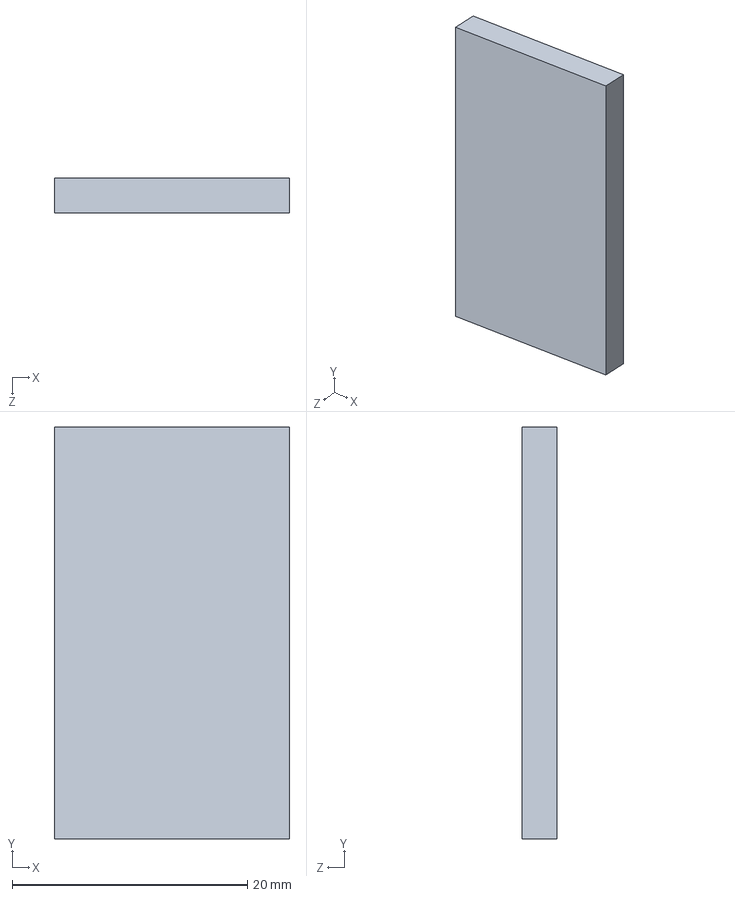
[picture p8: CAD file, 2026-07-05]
机械/widi.SLDPRT
20.0 x 35.0 x 3.00 mm

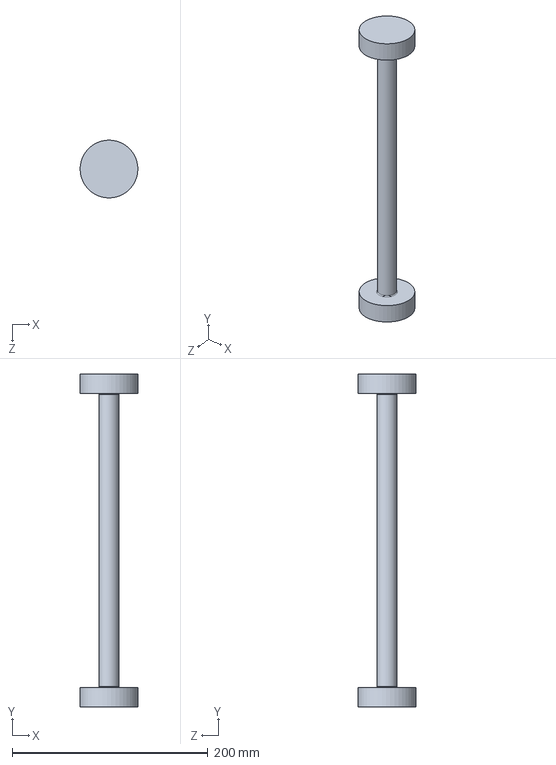
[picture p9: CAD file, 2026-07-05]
机械/岩芯.SLDPRT
59.0 x 340.0 x 59.0 mm

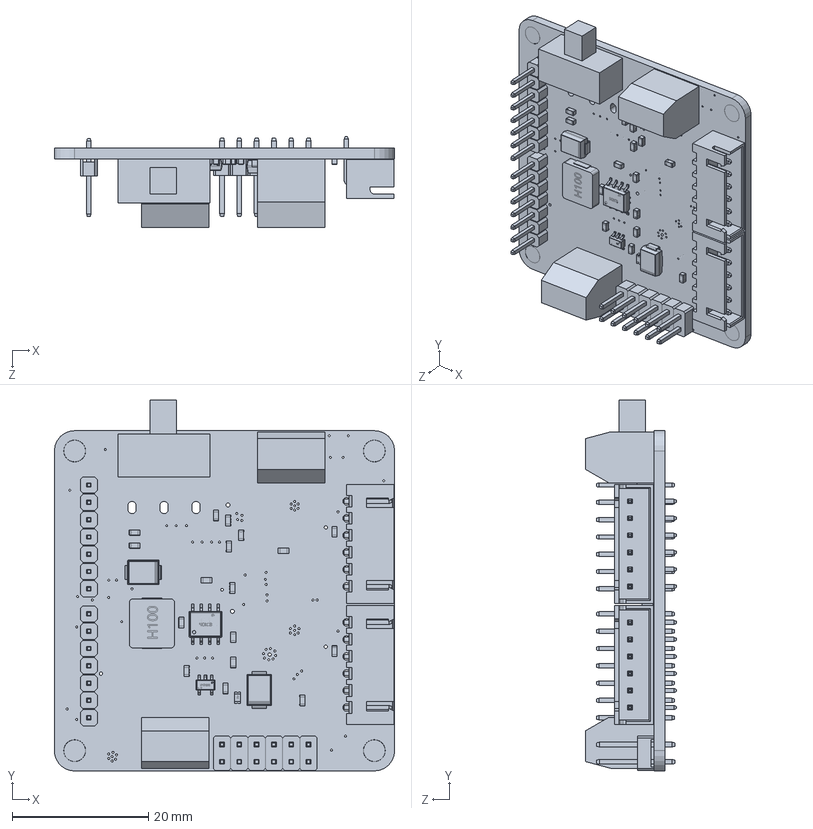
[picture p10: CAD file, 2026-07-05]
机械/TB6612双路驱动稳压模块（D153C).SLDPRT
50.0 x 54.5 x 13.4 mm

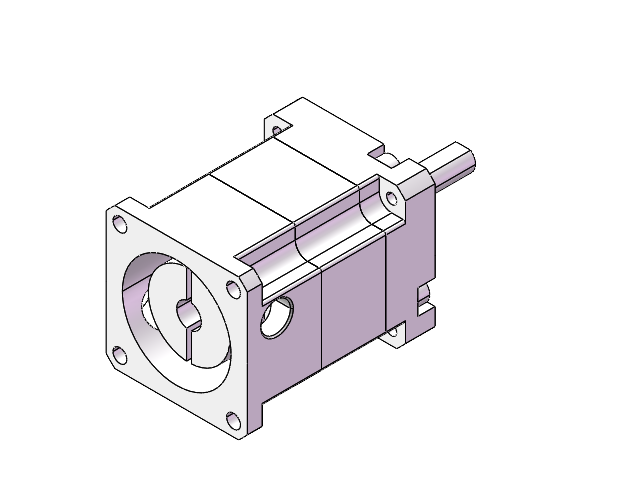
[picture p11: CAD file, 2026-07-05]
机械/HPB28-L1-(A)-S2-P2-（5-10-22-2.8-F23）.SLDASM
HPB28-______-5__.step
HPB28-__________.step
HPB28-______-C-L1-(5-10-22-2.8-F23).step

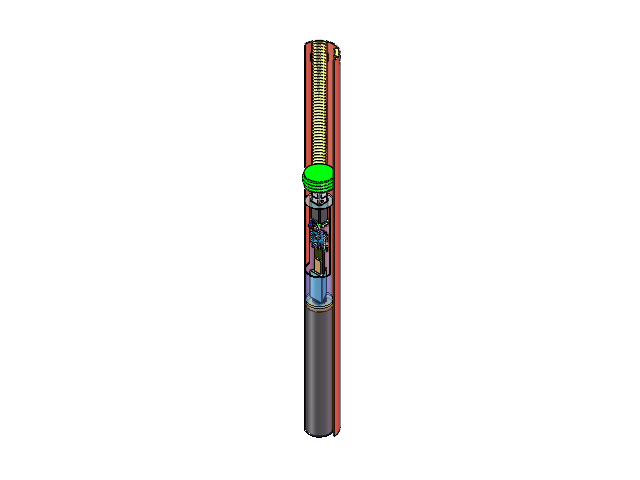
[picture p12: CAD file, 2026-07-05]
机械/28smd18.SLDASM
80外管
65外管
YDLIDAR SDM18 .STEP
YDLIDAR SDM18 ____ .STEP
SDM18____.STEP
________.STEP
ts-1145a-b-a_White.step.STEP x 2
PH2.0-WI-____.step.STEP x 4
PH2.0-WI-4P-0.step.STEP
PH2.0-WI-____-1.step.STEP x 8
PH2.0-WI-8P-3.step.STEP
Extruded.step.STEP
Extruded-4.step.STEP
28_STEPPER_MOTOR.STEP
SHIM_2.7x4x6.STEP x 4
ZDT_X28_V1.2.STEP
M2.5x9mm_Phillips.STEP x 4
WIRE_2.0.STEP
齿条
齿轮
TB6612双路驱动稳压模块（D153C)
三角电池
c8t6
widi
HPB28-______-5__.step
HPB28-__________.step
HPB28-______-C-L1-(5-10-22-2.8-F23).step
满岩芯

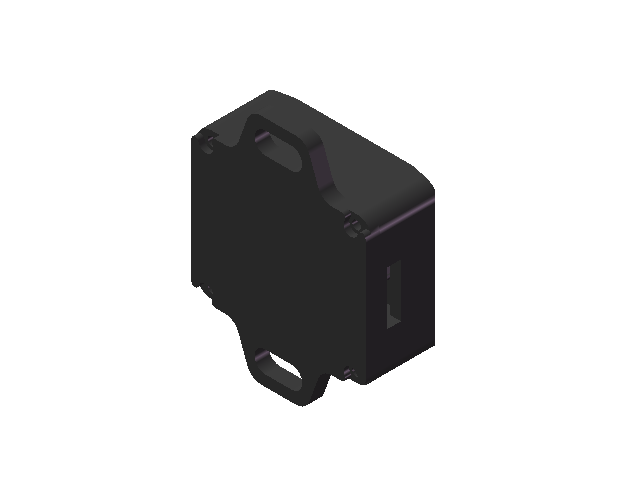
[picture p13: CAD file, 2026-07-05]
机械/SDM18（含外壳）.SLDASM
YDLIDAR SDM18 .STEP
YDLIDAR SDM18 ____ .STEP
SDM18____.STEP
________.STEP

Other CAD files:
机械/齿条.SLDPRT
机械/盖板上.SLDPRT
机械/支撑盖板.SLDPRT
机械/满岩芯.SLDPRT
机械/三角电池.SLDPRT
机械/盖板下.SLDPRT
机械/工程图/SolidWorks/65内管.SLDDRW
机械/工程图/SolidWorks/90外管.SLDDRW
机械/工程图/SolidWorks/模拟岩芯.SLDDRW
机械/工程图/SolidWorks/齿条.SLDDRW
机械/工程图/SolidWorks/齿轮.SLDDRW

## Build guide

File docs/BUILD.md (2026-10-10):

# Build and configuration / 构建与配置

[Repository guide / 仓库说明](../README.md) · [Manuscript correspondence / 论文对应关系](CODE_AVAILABILITY.md) · [Commands / 通信指令](PROTOCOL.md)

Use one of the final projects in `firmware/`. The main experiments reported in the manuscript used `wifi-once`; `wifi-retry` is also retained as an author-designated final implementation. Configure the actual parameters of the test being reproduced from the manuscript. The source-default differences reflect settings retained from different experimental periods.

使用`firmware/`中的一份最终工程。论文主要试验采用`wifi-once`，`wifi-retry`作为另一份最终实现保留。复现时按论文中对应试验的记录配置参数；两份源码默认值来自不同阶段的试验设置。

## Configure and build

1. Download the fixed [v1.0.0 firmware release](https://github.com/wangzifan396-wzf/electronic-position-signaling-mechanism/releases/tag/v1.0.0) or clone the repository, then select one variant under `firmware/`.
2. In that variant, copy `Core/Inc/wifi_config.example.h` to `Core/Inc/wifi_config.h`. Set the WiFi SSID/password and TCP server IP/port. The local header is ignored by Git; the example contains placeholders.
3. Open `MDK-ARM/SDM18-stm32-HAL.uvprojx` in Keil µVision. The saved project uses ARM Compiler **5.06 update 7, build 960**, the `STM32F103xE` definition and STM32F1 device pack **2.4.1**. Required HAL/CMSIS sources are included. Historical binaries and personal IDE settings are excluded from the two curated `firmware/` projects and the fixed release; the original development directories retain their uploaded contents.
4. Check the MCU, clock, memory map and Flash algorithm against the actual board before building. Configure a matching SWD programmer separately if downloading to hardware.
5. Start a TCP server on the configured host before the connection attempt. These two firmware folders do not contain the original host application or a browser interface. See [Interfaces and text protocol](PROTOCOL.md).

## 中文步骤

1. 下载固定v1.0.0固件发布版或克隆仓库，在`firmware/`中选择一份工程。
2. 将该工程的`Core/Inc/wifi_config.example.h`复制为`Core/Inc/wifi_config.h`，填写自己的WiFi名称、密码、TCP服务器IP和端口。本地头文件已加入Git忽略，示例占位值需自行替换。
3. 用Keil µVision打开`MDK-ARM/SDM18-stm32-HAL.uvprojx`。原工程使用ARM Compiler **5.06 update 7（build 960）**、`STM32F103xE`宏及STM32F1器件包**2.4.1**。HAL/CMSIS源码已保留。两份整理工程及固定发布版不含历史编译产物和个人IDE配置；原开发目录保留原上传内容。
4. 按实物核对MCU、晶振、内存区域和Flash下载算法后编译；需烧录时另行配置对应的SWD下载器。
5. 在所配置的主机启动TCP服务器，再进行连接。两份固件目录不包含原上位机程序或网页控制界面，指令及报文格式见通信协议。

## Original project settings / 原工程设置

The IOC and project Device records indicate **STM32F103RC/xE**, while some Flash/SVD settings still refer to C8 and historical ROM/RAM regions are retained. These are the original saved settings; check them against the actual MCU. Some source comments contain earlier thresholds, so read the executable definitions and current RAM settings when inspecting a run.

IOC和工程Device记录指向**STM32F103RC/xE**，部分Flash/SVD设置仍指向C8，并保留历史ROM/RAM区域。上述原工程设置需按实际MCU核对。源码个别注释保留了早期阈值，检查运行状态时应读取执行定义及当前RAM参数。

[Validation records](VALIDATION.md) describe the full rebuilds actually performed. [Implementation notes](KNOWN_LIMITATIONS.md) document the original control behavior. `SOURCE_MANIFEST.json` records the retained firmware files and the extraction of four network macros into the local configuration header; control algorithms were preserved.

验证记录提供已执行的完整重编译结果；实现说明记录原控制行为。`SOURCE_MANIFEST.json`记录保留文件及四项网络配置拆分，控制算法保持原样。

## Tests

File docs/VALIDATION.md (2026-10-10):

# Release validation / 发布验证

Checks below were performed for the `v1.0.0` publication snapshot on **2026-10-09**. They establish source packaging and build results, not new hardware performance.

## Source preservation and configuration

- Both retained original variants were compared with the author's local final directories. Before public packaging, the uploaded copies differed only in text line endings, with no substantive code differences.
- `SOURCE_MANIFEST.json` records original and release SHA-256 values for retained files. In each variant, only the four network macros in `Core/Src/main.c` are replaced with a local configuration include; a credential-free example header is added.
- All **33 source-file references** in each unchanged Keil project resolve within the published files.
- Real WiFi settings, historical compiled firmware, objects, personal IDE settings and debugger-specific files are excluded from the fixed `v1.0.0` release and the two curated `firmware/` projects. Each local `wifi_config.h` is ignored by Git. The original uploaded directories, restored to `main` on 2026-10-10, retain their historical files, including obsolete network settings that the owner confirmed are no longer in use.
- Original HAL/CMSIS licenses and file-level copyright notices are retained. The project MIT license is separate from those component licenses.

## Complete rebuild

The two publication variants were copied to separate build-check directories. In each copy, `wifi_config.example.h` was copied to `wifi_config.h` without inserting real credentials. Each project received one full Keil rebuild using the saved **ARM Compiler 5.06 update 7, build 960**. Both linked successfully and generated AXF/HEX in the temporary build directories. Source and project hashes remained unchanged. Those binaries are not release assets.

| Variant | Errors | Warnings | Result |
|---|---:|---:|---|
| `wifi-once` | 0 | 36 | Successful link; warnings retained |
| `wifi-retry` | 0 | 34 | Successful link; warnings retained |

Each variant reports 13 missing-final-newline warnings (`#1-D`, including repeated header inclusion). The remaining 23/21 warnings (`#870-D`) concern Chinese/Unicode or emoji `printf` string literals. They are not exclusively comment warnings. No claim is made that serial character rendering was verified. Warning-only µVision exit code was 1.

## Scope

The release checks did not flash hardware, move a motor, connect to the author's network, test TCP reconnection, measure timing, or repeat the paper's experiments. Successful compilation does not resolve the implementation details in [Known limitations](KNOWN_LIMITATIONS.md).

## 中文

本次核对确认：两最终工程与上传内容实质一致；每版33个Keil源码引用均存在；除四项网络配置拆分及新增示例头文件外，保留文件未改写控制逻辑。原凭据、旧编译固件及个人调试配置未纳入固定 `v1.0.0` 发布版和两份整理后的 `firmware/` 工程；2026-10-10 恢复到 `main` 的原上传目录保留原有历史文件。第三方许可与版权声明保留。

采用工程原定ARMCC 5.06 update 7（build 960），在独立副本中分别完整重编译一次。一次版0错误、36警告；重试版0错误、34警告，均成功链接。警告为末尾换行及中文/Unicode输出字符串，未自行改写。此次没有烧录和新增实物测试，不能以编译通过替代硬件、通信、时序或论文性能验证。

## Repository preservation checks — 2026-10-10 / 仓库资料完整性核对

The material restoration was published at commit [`c0c7b40`](https://github.com/wangzifan396-wzf/electronic-position-signaling-mechanism/commit/c0c7b40e8158e27fce74b14fde9e506d6e431814). The following file-preservation checks were recorded for that update:

- All 24 original project directories and their 16,277 files match the original snapshot in Git blobs, file modes and sizes, including the 16 original mechanical model files.
- All 542 files in the two final `firmware/` projects remain unchanged from the fixed release; the `v1.0.0` tag and release assets are unchanged.
- The 20 added drawing-related original files match their local source files in SHA-256 and size. Public downloads were checked against the same records; the published file list is in [DRAWING_MANIFEST.json](../%E6%9C%BA%E6%A2%B0/%E5%B7%A5%E7%A8%8B%E5%9B%BE/DRAWING_MANIFEST.json).
- The 108 local links in the seven documentation files prepared for the restoration resolved successfully.

These checks establish file preservation and access. They did not add hardware experiments, repeat manuscript measurements, or rebuild the SolidWorks assemblies and their external references.

此次资料恢复发布于上述提交。已核对：24 个原项目目录中的 16,277 个文件（含 16 个原机械模型）与原快照的 Git 对象、文件模式和大小一致；两份最终固件中的 542 个文件、固定标签和发布附件不变；20 份新增图纸相关原文件及公开下载内容的 SHA-256 和大小与原件一致；当次准备的七份文档共 108 个内部链接均有效。该核对说明文件完整性与可访问性，未新增实物试验、重做论文测量或重建 SolidWorks 装配体及其外部引用。

## Repeat the packaging check / 重复源码完整性检查

With Python 3, run `python tools/verify_release.py` from the extracted repository. It verifies the retained snapshot hashes, configuration extraction, licenses and all Keil source references without requiring a third-party Python package. This check does not compile the firmware or test hardware.

解压仓库后可用Python 3运行上述命令，核对保留文件哈希、配置拆分、许可及Keil源码引用；无需安装第三方Python包。该检查不编译固件，也不进行实物测试。

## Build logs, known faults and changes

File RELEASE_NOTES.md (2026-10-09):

# v1.0.0 — Final firmware source release

This release contains the two author-designated final STM32F1 firmware versions for electronic position signaling and inner-tube control:

- `wifi-once`: one startup WiFi connection attempt; default landed/upper/core-full thresholds of 360/700/70 mm.
- `wifi-retry`: periodic retries while the connection flag is zero; defaults of 400/800/100 mm.

The control logic is retained. Network credentials are supplied through a local ignored configuration file. Each source archive includes the required Keil/CubeMX files, retained HAL/CMSIS sources, license notices, configuration example and source manifest. Historical binaries and personal debugger/IDE files are excluded.

See the README and `docs/VALIDATION.md` for actual build checks and `docs/KNOWN_LIMITATIONS.md` for implementation details. The release does not introduce new hardware test results. The original code's limitations have not been silently repaired.

## 中文

首次整理公开作者指定的两个最终固件版本，分别采用启动时单次WiFi连接与连接失败后的定时重试策略。默认参数分别列明；控制逻辑保持原最终版。网络配置改为本地文件和示例模板；提供中英文README、接口说明、源码追溯和软件引用信息。原创贡献采用MIT，第三方组件保留原许可。

论文引用建议指向本发布页。两份独立源码压缩包对应两个版本，不含原WiFi密码和历史编译固件。

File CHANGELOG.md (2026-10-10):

# Changelog

## Paper-supporting documentation update — 2026-10-10

- Reframed the repository overview and navigation around the manuscript's supporting firmware, mechanical models and engineering drawings.
- Recorded the author's confirmation that the manuscript's main experiments primarily used `firmware/wifi-once`; `firmware/wifi-retry` remains an alternative final source snapshot from a different experimental period.
- Clarified that the snapshots retain their respective startup defaults, while the manuscript reports the experimental settings to use for reproduction. Documented the five RAM-only settings supported by runtime commands and distinguished them from compile-time constants.
- Updated the code/material availability wording and clarified which materials are in the fixed firmware release and which were added to `main`.
- This update changes documentation only. Original source code, startup defaults, historical project files, models, drawings, the `v1.0.0` tag and release assets are unchanged.

中文：按论文配套研究资料优化仓库说明与入口；记录作者确认的主要试验版本为一次连接版，重试连接版保留另一实验阶段的最终源码。两版初始化默认值原样保留，复现参数以论文为准；明确五项运行时 RAM 参数与编译期常量的区别。此次仅修改说明文档，源码、默认值、历史项目、模型、图纸及固定固件标签和发布附件不变。

## Repository material update — 2026-10-10

- Restored all 24 originally uploaded root directories from commit `5d6e080df02d82a73eb847e18485b2bdb33146d4`, preserving their files unchanged, including all 16 original mechanical model files.
- Kept the two curated final firmware projects in `firmware/wifi-once` and `firmware/wifi-retry` as the latest firmware. The restored original final-version folders are the original upload snapshots.
- Added the author's thesis drawing set under `机械/工程图`: five original PDFs, five original PNGs, five original SolidWorks drawings, the same-source rack model and four original thesis images, with SHA-256 values in `DRAWING_MANIFEST.json`.
- Added bilingual mechanical/drawing guides and an index of all original project directories. Clarified the MIT and third-party license scope across curated firmware, restored uploads and drawings.
- This is a `main`-branch repository update. The `v1.0.0` tag, release assets, software citation metadata and two curated firmware projects are unchanged; the new drawing material is not in the existing `v1.0.0` archives.

中文：全部24个原目录及16个机械模型已原样恢复；两份最终固件继续作为最新版。新增论文终稿对应的工程图及索引说明，原文件未重绘。此次仅更新仓库`main`资料，既有`v1.0.0`标签、发布附件、软件引用信息及规范固件工程不变。

## v1.0.0 — 2026-10-09

- First curated public source release containing both author-designated final variants: `wifi-once` and `wifi-retry`.
- Retained the final control logic, thresholds, interfaces, source files and Keil/CubeMX project records.
- Extracted hardcoded network settings into an ignored local header and added an example configuration; excluded historical binaries and personal IDE/debug files.
- Added bilingual documentation, protocol and implementation notes, software citation metadata, source hashes and MIT/third-party license notices.
- This is a publication snapshot, not a claim of new experiments or fixes to the original control implementation.

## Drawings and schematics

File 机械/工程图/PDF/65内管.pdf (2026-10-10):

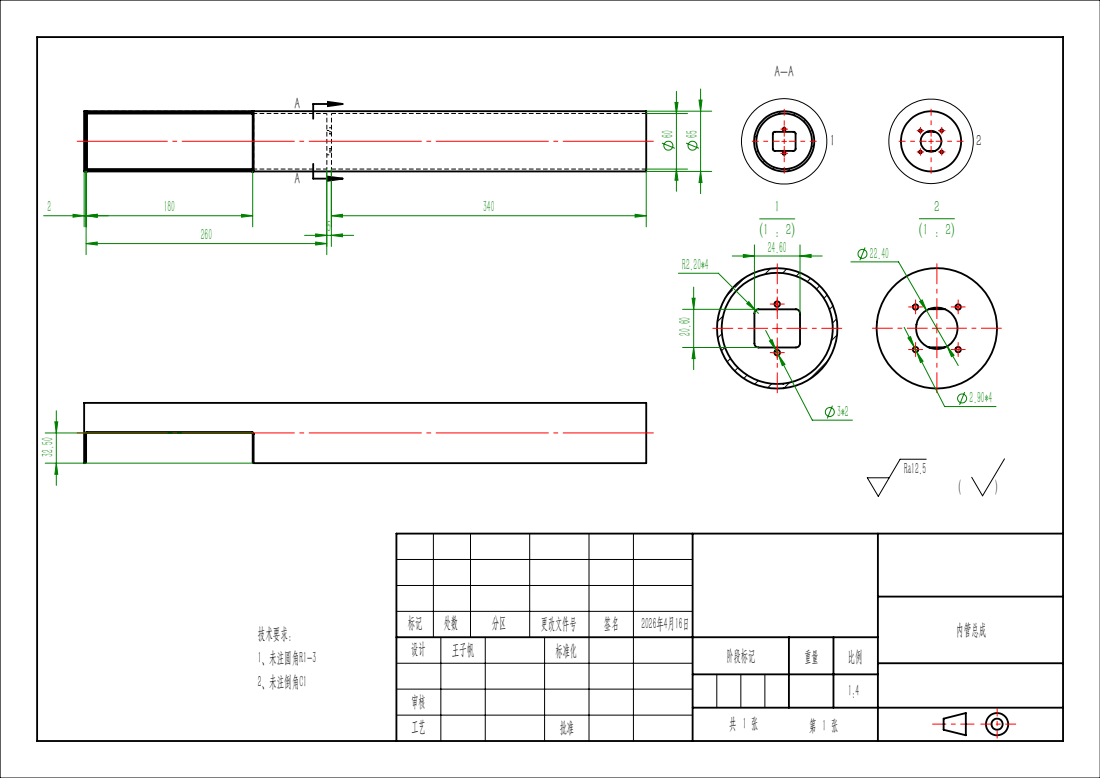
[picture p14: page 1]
阶段标记

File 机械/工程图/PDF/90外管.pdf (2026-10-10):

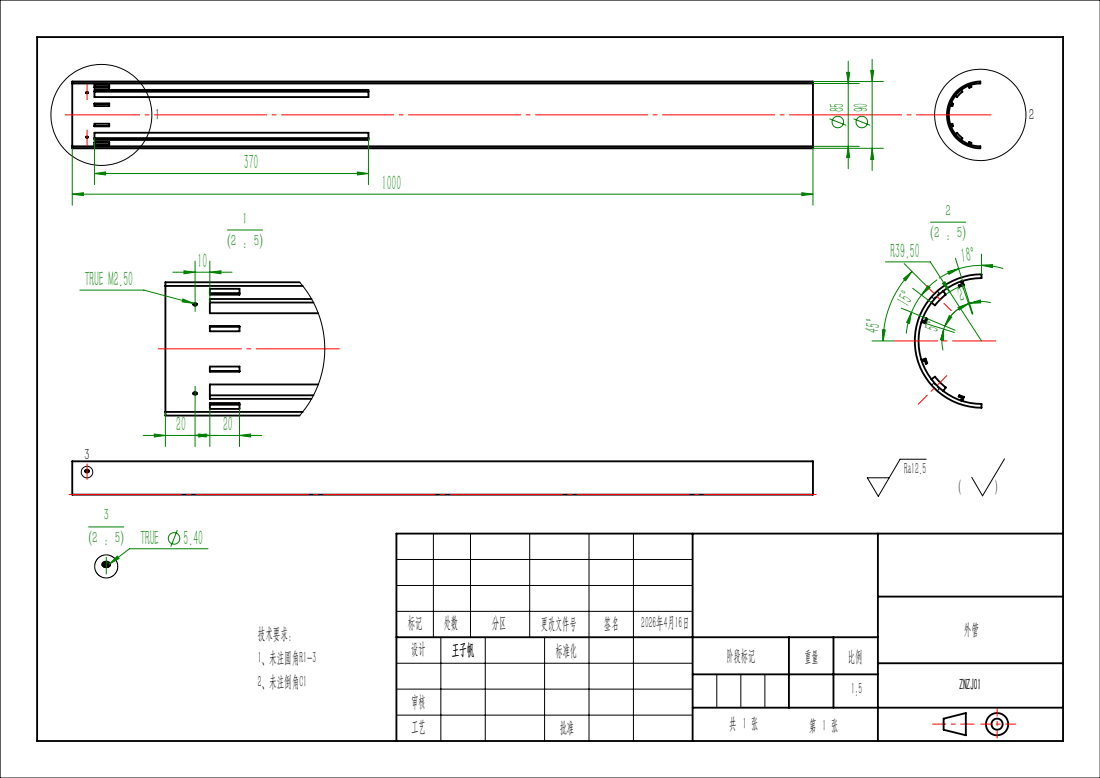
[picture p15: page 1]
TRUE M2.50; TRUE 5.40; 阶段标记

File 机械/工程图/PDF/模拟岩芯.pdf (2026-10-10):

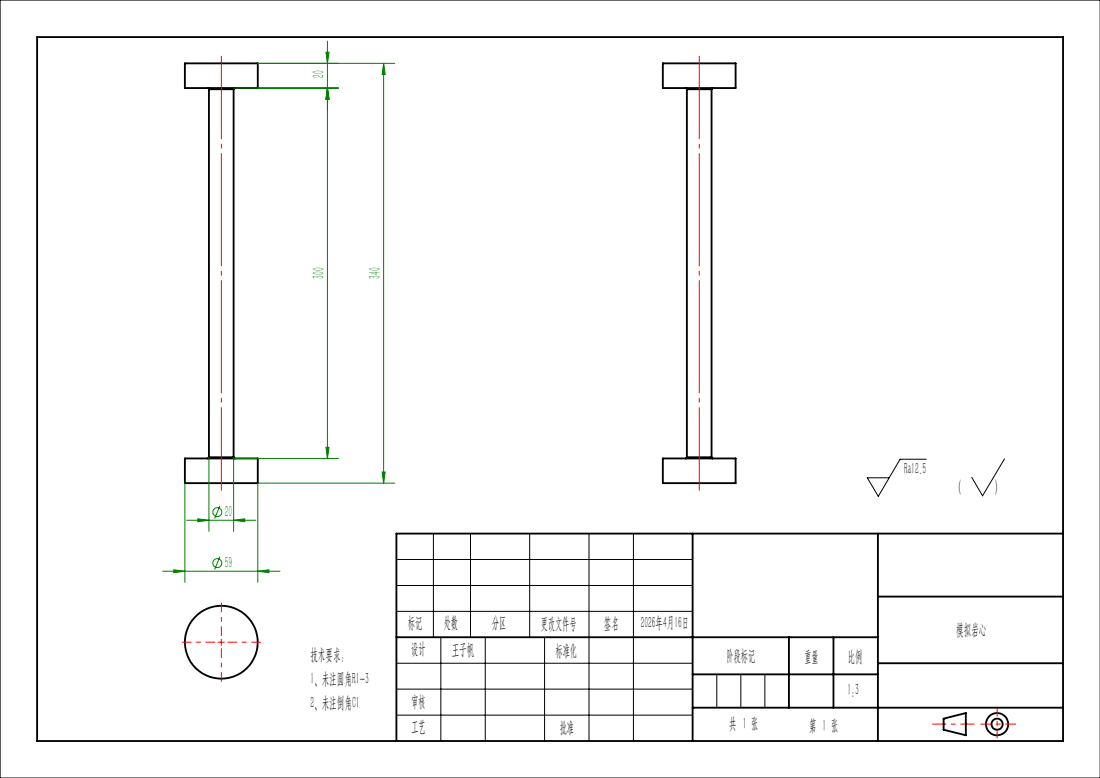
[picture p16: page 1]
阶段标记

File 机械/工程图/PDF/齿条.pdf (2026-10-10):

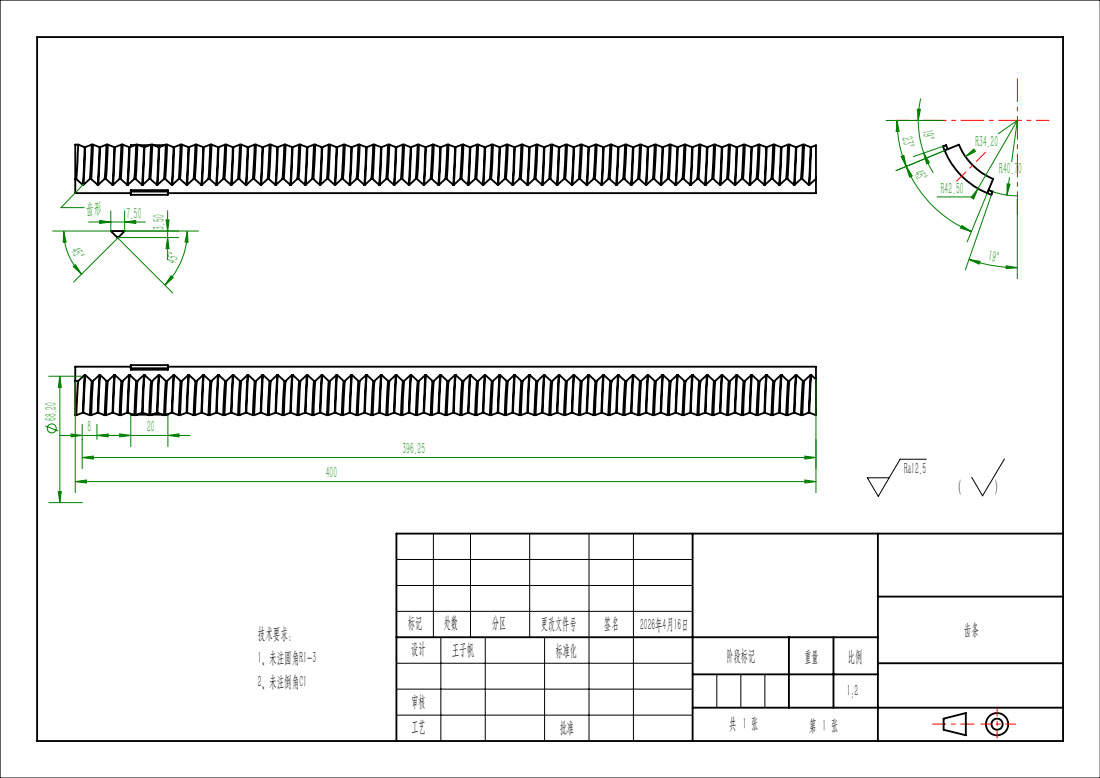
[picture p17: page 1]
阶段标记

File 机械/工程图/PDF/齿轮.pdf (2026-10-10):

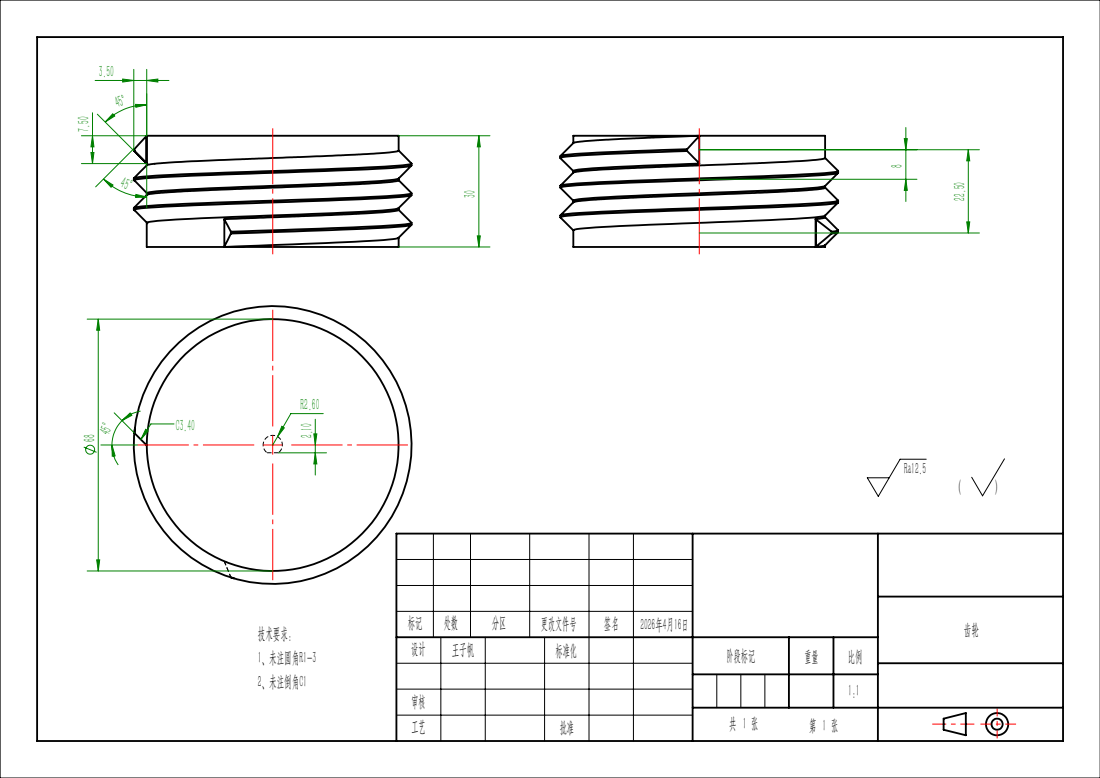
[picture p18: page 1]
阶段标记

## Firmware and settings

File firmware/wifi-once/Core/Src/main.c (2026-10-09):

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
/* Includes ------------------------------------------------------------------*/
#include "main.h"
#include "dma.h"
#include "tim.h"
#include "usart.h"
#include "gpio.h"

/* USER CODE BEGIN Includes */
#include <stdbool.h>
#include <stdio.h>
#include <string.h>
#include <stdlib.h>
/* USER CODE END Includes */

/* USER CODE BEGIN PD */
// 电机引脚定义
#define MOTOR_EN_PIN   GPIO_PIN_5      // 使能引脚
#define MOTOR_STP_PIN  GPIO_PIN_6      // 脉冲引脚
#define MOTOR_DIR_PIN  GPIO_PIN_7      // 方向引脚
#define MOTOR_PORT     GPIOA

// 钻具工作模式
#define MODE_IDLE       0    // 空闲
#define MODE_DOWN       1    // 正转下钻
#define MODE_UP         2    // 反转上提
#define MODE_PAUSE      3    // 暂停

// 默认阈值定义（单位：mm）
#define DEFAULT_THRESHOLD_GROUND    700     // 默认地面阈值(675)
#define DEFAULT_THRESHOLD_IN_PLACE  360     // 默认内管到位阈值(340)
#define DEFAULT_THRESHOLD_FULL      70     // 满芯阈值（小于100mm为满）
#define DEFAULT_THRESHOLD_STUCK     2       // 卡芯判断差值（2mm以内为卡）

// 数组大小定义
#define DIST_ARRAY_SIZE     10      // 10个相邻测距的数组

// 时间定义（单位：ms）
#define MEASURE_INTERVAL        100     // 100ms测一次距离
#define PAUSE_TIME_IN_PLACE     5000    // 内管到位暂停时间（5秒）
#define PAUSE_TIME_CORE         3000    // 卡芯/满芯暂停时间（3秒）
#define DEFAULT_MOTOR_SPEED     100    // 默认电机速度（延时值，越小越快）

// ==================== WiFi配置 ====================
#define WIFI_UART_HANDLE      &huart3      // USART3连接WiFi
#define WIFI_RST_PIN          GPIO_PIN_9   // WiFi复位引脚（PB9）
#define WIFI_RST_PORT         GPIOB
#define WIFI_IO_PIN           GPIO_PIN_8   // IO引脚（PB8），悬空即可

// WiFi连接参数
#include "wifi_config.h"
/* USER CODE END PD */


/* USER CODE BEGIN PV */
// 电机控制变量
__IO int32_t pulse_count = 0;           // 脉冲计数
__IO uint8_t motor_status = MODE_IDLE;   // 电机当前状态

// ==================== 可修改的参数（支持远程修改） ====================
__IO uint16_t threshold_ground = DEFAULT_THRESHOLD_GROUND;     // 地面阈值
__IO uint16_t threshold_in_place = DEFAULT_THRESHOLD_IN_PLACE; // 内管到位阈值
__IO uint16_t threshold_full = DEFAULT_THRESHOLD_FULL;         // 满芯阈值
__IO uint16_t threshold_stuck = DEFAULT_THRESHOLD_STUCK;       // 卡芯差值阈值
__IO uint16_t motor_speed = DEFAULT_MOTOR_SPEED;               // 电机转速（脉冲延时值）

// 手动控制标志
__IO uint8_t manual_control = 0;      // 0-自动模式 1-手动模式
__IO uint8_t manual_cmd = 0;          // 手动命令：1-下钻 2-上提 3-停止

// 钻具控制变量
__IO uint8_t drill_mode = MODE_IDLE;     // 钻具工作模式
__IO uint32_t pause_start_time = 0;      // 暂停开始时间
__IO uint8_t pause_trigger_reason = 0;   // 暂停原因：1-卡芯 2-满芯

// 重要：标记当前是否在反转上提阶段
__IO uint8_t is_reversing = 0;           // 0-不是反转 1-正在反转上提

// 到位标记：表示已经到达阈值，开始卡芯/满芯判断
__IO uint8_t is_in_place = 0;            // 0-未到位 1-已到位

// 测距数组（用于卡芯和满芯判断）
__IO uint16_t dist_array[DIST_ARRAY_SIZE] = {0};
__IO uint8_t dist_array_index = 0;
__IO uint8_t dist_array_full = 0;

// 传感器距离（从sdm18.c获取）
extern uint16_t gSDM18_Distance;

// WiFi连接标志
__IO uint8_t wifi_connected = 0;
__IO uint8_t wifi_attempted = 0;

// 指令接收缓冲区
uint8_t cmd_buffer[256];
uint8_t cmd_index = 0;
uint8_t rx_byte = 0;
volatile uint8_t cmd_ready = 0;  // 指令处理标志，在主循环中处理
/* USER CODE END PV */

void SystemClock_Config(void);
/* USER CODE BEGIN PFP */
// 函数声明
void Motor_GPIO_Init(void);
void Motor_Set_Direction(uint8_t dir);
void Motor_Generate_Pulse(void);
void Drill_Control(uint16_t dist);
void Update_Distance_Array(uint16_t dist);
uint8_t Check_Stuck(void);
uint8_t Check_Full(void);
void Print_Status(uint16_t dist);

// WiFi相关函数声明
void WiFi_GPIO_Init(void);
void WiFi_Reset(void);
uint8_t WiFi_SendAT(const char* cmd, const char* expected, uint32_t timeout);
void WiFi_Connect(void);
void WiFi_SendData(uint8_t* data, uint16_t len);
void WiFi_SendStatus(uint16_t dist, uint8_t mode, uint8_t in_place, uint8_t reversing, 
                      uint16_t avg, uint16_t diff);
void Parse_Command(char* cmd);
/* USER CODE END PFP */

/**
  * @brief  The application entry point.
  * @retval int
  */
int main(void)
{
  HAL_Init();
  SystemClock_Config();
  MX_GPIO_Init();
  MX_DMA_Init();
  MX_USART1_UART_Init();
  MX_USART2_UART_Init();
  MX_TIM3_Init();
  MX_USART3_UART_Init();
  
  /* USER CODE BEGIN 2 */
  BSP_init();  // 传感器初始化
  
  // 电机GPIO初始化
  Motor_GPIO_Init();
  
  // WiFi模块引脚初始化
  WiFi_GPIO_Init();
  
  // 复位WiFi模块
  WiFi_Reset();
  HAL_Delay(1000);
  
  // 尝试连接WiFi（只尝试一次）
  printf("\r\n尝试连接WiFi...\r\n");
  WiFi_Connect();
  wifi_attempted = 1;
  
  if(wifi_connected)
  {
      printf("WiFi连接成功，数据将无线传输\r\n");
      printf("可发送指令: SET_IN_PLACE|xxx, SET_GROUND|xxx, SET_SPEED|xxx, GET_PARAMS, CMD_DOWN, CMD_UP, CMD_STOP, CMD_RESET\r\n");
      
      // 启动USART3接收中断（用于接收APP指令）
      HAL_UART_Receive_IT(&huart3, &rx_byte, 1);
  }
  else
  {
      printf("WiFi连接失败，系统将独立运行（如需WiFi请按复位键）\r\n");
  }
  
  // 清空距离数组
  memset((void*)dist_array, 0, sizeof(dist_array));
  
  printf("\r\n====================================\r\n");
  printf("新型钻具机构控制系统启动\r\n");
  if(wifi_connected)
  {
      printf("WiFi模式：已连接 %s:%s\r\n", SERVER_IP, SERVER_PORT);
  }
  else
  {
      printf("WiFi模式：未连接（独立运行）\r\n");
  }
  printf("当前参数：到位=%dmm 地面=%dmm 满芯=<%dmm 卡芯差值<%dmm\r\n", 
         threshold_in_place, threshold_ground, threshold_full, threshold_stuck);
  printf("电机速度：延时=%d (越小越快)\r\n", motor_speed);
  printf("测距间隔：100ms\r\n");
  printf("暂停时间：内管到位=%dms 卡芯/满芯=%dms\r\n", PAUSE_TIME_IN_PLACE, PAUSE_TIME_CORE);
  printf("====================================\r\n\r\n");
  /* USER CODE END 2 */

  /* Infinite loop */
  /* USER CODE BEGIN WHILE */
  while (1)
  {
    BSP_Loop();  // 处理传感器数据
    
    // 产生电机脉冲
    Motor_Generate_Pulse();
    
    // 处理接收到的指令（在主循环中执行，不在中断中，避免死锁）
    if(cmd_ready)
    {
        cmd_ready = 0;
        Parse_Command((char*)cmd_buffer);
    }
    
    // 每100ms执行一次控制逻辑
    static uint32_t last_control = 0;
    if(HAL_GetTick() - last_control >= MEASURE_INTERVAL)
    {
        last_control = HAL_GetTick();
        
        uint16_t current_dist = gSDM18_Distance;
        Update_Distance_Array(current_dist);
        Drill_Control(current_dist);
        Print_Status(current_dist);
    }
    
    /* USER CODE END WHILE */
    /* USER CODE BEGIN 3 */
  }
  /* USER CODE END 3 */
}

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
/* USER CODE BEGIN 4 */

/**
  * @brief 电机GPIO初始化
  */
void Motor_GPIO_Init(void)
{
    __HAL_RCC_GPIOA_CLK_ENABLE();
    
    GPIO_InitTypeDef GPIO_InitStruct = {0};
    GPIO_InitStruct.Pin = MOTOR_EN_PIN | MOTOR_STP_PIN | MOTOR_DIR_PIN;
    GPIO_InitStruct.Mode = GPIO_MODE_OUTPUT_PP;
    GPIO_InitStruct.Pull = GPIO_NOPULL;
    GPIO_InitStruct.Speed = GPIO_SPEED_FREQ_LOW;
    HAL_GPIO_Init(MOTOR_PORT, &GPIO_InitStruct);
    
    HAL_GPIO_WritePin(MOTOR_PORT, MOTOR_EN_PIN, GPIO_PIN_SET);
    HAL_GPIO_WritePin(MOTOR_PORT, MOTOR_STP_PIN, GPIO_PIN_RESET);
    HAL_GPIO_WritePin(MOTOR_PORT, MOTOR_DIR_PIN, GPIO_PIN_RESET);
}

/**
  * @brief 设置电机方向
  */
void Motor_Set_Direction(uint8_t dir)
{
    if(dir == MODE_DOWN)
    {
        HAL_GPIO_WritePin(MOTOR_PORT, MOTOR_DIR_PIN, GPIO_PIN_SET);
    }
    else if(dir == MODE_UP)
    {
        HAL_GPIO_WritePin(MOTOR_PORT, MOTOR_DIR_PIN, GPIO_PIN_RESET);
    }
}

/**
  * @brief 产生电机脉冲（速度可调）
  */
void Motor_Generate_Pulse(void)
{
    if(motor_status != MODE_DOWN && motor_status != MODE_UP)
        return;
    
    for(volatile int i = 0; i < motor_speed; i++)
    {
        __NOP();
    }
    
    HAL_GPIO_TogglePin(MOTOR_PORT, MOTOR_STP_PIN);
    pulse_count++;
}

/**
  * @brief 更新距离数组
  */
void Update_Distance_Array(uint16_t dist)
{
    dist_array[dist_array_index] = dist;
    dist_array_index++;
    if(dist_array_index >= DIST_ARRAY_SIZE)
    {
        dist_array_index = 0;
        dist_array_full = 1;
    }
}

/**
  * @brief 检查是否卡芯
  */
uint8_t Check_Stuck(void)
{
    if(!dist_array_full) return 0;
    
    uint16_t max_dist = 0, min_dist = 65535;
    for(int i = 0; i < DIST_ARRAY_SIZE; i++)
    {
        if(dist_array[i] > max_dist) max_dist = dist_array[i];
        if(dist_array[i] < min_dist) min_dist = dist_array[i];
    }
    
    if((max_dist - min_dist) < threshold_stuck) return 1;
    return 0;
}

/**
  * @brief 检查是否满芯
  */
uint8_t Check_Full(void)
{
    if(!dist_array_full) return 0;
    
    for(int i = 0; i < DIST_ARRAY_SIZE; i++)
    {
        if(dist_array[i] >= threshold_full) return 0;
    }
    return 1;
}

/**
  * @brief 钻具控制主逻辑（手动模式优先）
  */
void Drill_Control(uint16_t dist)
{
    if(dist == 0) return;
    
    // ==================== 手动模式优先 ====================
    if(manual_control == 1)
    {
        if(manual_cmd == 1)  // 手动下钻
        {
            if(motor_status != MODE_DOWN)
            {
                motor_status = MODE_DOWN;
                drill_mode = MODE_DOWN;
                is_reversing = 0;
                is_in_place = 0;
                Motor_Set_Direction(MODE_DOWN);
                printf("手动: 下钻\r\n");
                WiFi_SendData((uint8_t*)"!!! MANUAL: DRILLING START !!!\r\n", 35);
            }
        }
        else if(manual_cmd == 2)  // 手动上提
        {
            if(motor_status != MODE_UP)
            {
                motor_status = MODE_UP;
                drill_mode = MODE_UP;
                is_reversing = 1;
                is_in_place = 0;
                Motor_Set_Direction(MODE_UP);
                printf("手动: 上提\r\n");
                WiFi_SendData((uint8_t*)"!!! MANUAL: REVERSING START !!!\r\n", 35);
            }
        }
        else if(manual_cmd == 3)  // 急停
        {
            if(motor_status != MODE_IDLE)
            {
                motor_status = MODE_IDLE;
                drill_mode = MODE_IDLE;
                is_reversing = 0;
                is_in_place = 0;
                HAL_GPIO_WritePin(MOTOR_PORT, MOTOR_STP_PIN, GPIO_PIN_RESET);
                printf("手动: 急停\r\n");
                WiFi_SendData((uint8_t*)"!!! EMERGENCY STOP !!!\r\n", 25);
            }
        }
        return;  // 手动模式下不执行自动逻辑
    }
    
    // ==================== 自动模式 ====================
    
    /********** 处理暂停状态 **********/
    if(drill_mode == MODE_PAUSE)
    {
        if(HAL_GetTick() - pause_start_time >= PAUSE_TIME_CORE)
        {
            drill_mode = MODE_UP;
            motor_status = MODE_UP;
            is_reversing = 1;
            is_in_place = 0;
            Motor_Set_Direction(MODE_UP);
            printf("⬆️ 暂停结束，反转上提（目标%dmm）\r\n", threshold_ground);
            WiFi_SendData((uint8_t*)"!!! ACTION: REVERSING START !!!\r\n", 35);
        }
        return;
    }
    
    /********** 检查是否在地面阈值 **********/
    if(dist >= threshold_ground)
    {
        if(drill_mode != MODE_IDLE || is_reversing != 0)
        {
            drill_mode = MODE_IDLE;
            motor_status = MODE_IDLE;
            is_reversing = 0;
            is_in_place = 0;
            printf("🏁 到达地面阈值 %dmm，停止\r\n", threshold_ground);
            printf("----------------------------------------\r\n");
            WiFi_SendData((uint8_t*)"!!! STATUS: AT GROUND !!!\r\n", 29);
        }
        return;
    }
    
    /********** 反转阶段 **********/
    if(is_reversing == 1)
    {
        if(drill_mode != MODE_UP)
        {
            drill_mode = MODE_UP;
            motor_status = MODE_UP;
            Motor_Set_Direction(MODE_UP);
        }
        return;
    }
    
    /********** 判断是否到位 **********/
    if(dist <= threshold_in_place)
    {
        if(drill_mode != MODE_IDLE)
        {
            drill_mode = MODE_IDLE;
            motor_status = MODE_IDLE;
            printf("⏹️ 内管到位 %dmm，停止\r\n", dist);
            char alert[64];
            sprintf(alert, "*** STATUS: IN_PLACE (dist=%dmm) ***\r\n", dist);
            WiFi_SendData((uint8_t*)alert, strlen(alert));
        }
        
        if(is_in_place == 0)
        {
            is_in_place = 1;
            printf("🔍 开始卡芯/满芯监测...\r\n");
            
            uint32_t pause_start = HAL_GetTick();
            while(HAL_GetTick() - pause_start < PAUSE_TIME_IN_PLACE)
            {
                HAL_Delay(10);
            }
        }
        
        if(is_in_place == 1)
        {
            if(Check_Full())
            {
                drill_mode = MODE_PAUSE;
                motor_status = MODE_IDLE;
                pause_start_time = HAL_GetTick();
                pause_trigger_reason = 2;
                printf("⏸️ 满芯！暂停3秒后反转上提\r\n");
                WiFi_SendData((uint8_t*)"!!! ALERT: CORE FULL !!!\r\n", 28);
                return;
            }
            
            if(Check_Stuck())
            {
                drill_mode = MODE_PAUSE;
                motor_status = MODE_IDLE;
                pause_start_time = HAL_GetTick();
                pause_trigger_reason = 1;
                printf("⚠️ 卡芯！暂停3秒后反转上提\r\n");
                WiFi_SendData((uint8_t*)"!!! ALERT: CORE STUCK !!!\r\n", 28);
                return;
            }
        }
        return;
    }
    
    /********** 距离>阈值，还没到位 **********/
    if(dist > threshold_in_place)
    {
        if(drill_mode != MODE_DOWN)
        {
            drill_mode = MODE_DOWN;
            motor_status = MODE_DOWN;
            is_in_place = 0;
            Motor_Set_Direction(MODE_DOWN);
            printf("⬇️ 距离=%dmm > %dmm，正转下钻\r\n", dist, threshold_in_place);
        }
    }
}

// ==================== 指令解析函数 ====================

/**
  * @brief 解析APP发来的指令
  */
void Parse_Command(char* cmd)
{
    // 限制指令长度，防止缓冲区溢出
    if(strlen(cmd) > 100)
    {
        printf("指令太长，忽略\r\n");
        return;
    }
    
    printf("收到指令: %s\r\n", cmd);
    
    // 修改内管到位阈值
    if(strstr(cmd, "SET_IN_PLACE|") != NULL)
    {
        uint16_t val = atoi(cmd + 13);
        if(val >= 100 && val <= 1000)
        {
            threshold_in_place = val;
            printf("内管到位阈值已修改为: %dmm\r\n", threshold_in_place);
            WiFi_SendData((uint8_t*)"OK|IN_PLACE_CHANGED\r\n", 23);
        }
        else
        {
            WiFi_SendData((uint8_t*)"ERROR|INVALID_VALUE\r\n", 22);
        }
        return;
    }
    
    // 修改地面阈值
    if(strstr(cmd, "SET_GROUND|") != NULL)
    {
        uint16_t val = atoi(cmd + 11);
        if(val >= 500 && val <= 1500)
        {
            threshold_ground = val;
            printf("地面阈值已修改为: %dmm\r\n", threshold_ground);
            WiFi_SendData((uint8_t*)"OK|GROUND_CHANGED\r\n", 22);
        }
        else
        {
            WiFi_SendData((uint8_t*)"ERROR|INVALID_VALUE\r\n", 22);
        }
        return;
    }
    
    // 修改满芯阈值
    if(strstr(cmd, "SET_FULL|") != NULL)
    {
        uint16_t val = atoi(cmd + 9);
        if(val >= 20 && val <= 200)
        {
            threshold_full = val;
            printf("满芯阈值已修改为: %dmm\r\n", threshold_full);
            WiFi_SendData((uint8_t*)"OK|FULL_CHANGED\r\n", 20);
        }
        else
        {
            WiFi_SendData((uint8_t*)"ERROR|INVALID_VALUE\r\n", 22);
        }
        return;
    }
    
    // 修改卡芯差值阈值
    if(strstr(cmd, "SET_STUCK|") != NULL)
    {
        uint16_t val = atoi(cmd + 10);
        if(val >= 1 && val <= 50)
        {
            threshold_stuck = val;
            printf("卡芯差值阈值已修改为: %dmm\r\n", threshold_stuck);
            WiFi_SendData((uint8_t*)"OK|STUCK_CHANGED\r\n", 21);
        }
        else
        {
            WiFi_SendData((uint8_t*)"ERROR|INVALID_VALUE\r\n", 22);
        }
        return;
    }
    
    // 修改电机速度
    if(strstr(cmd, "SET_SPEED|") != NULL)
    {
        uint16_t val = atoi(cmd + 10);
        if(val >= 100 && val <= 5000)
        {
            motor_speed = val;
            printf("电机速度已修改: 延时=%d\r\n", motor_speed);
            WiFi_SendData((uint8_t*)"OK|SPEED_CHANGED\r\n", 21);
        }
        else
        {
            WiFi_SendData((uint8_t*)"ERROR|INVALID_VALUE\r\n", 22);
        }
        return;
    }
    
    // 查询当前参数
    if(strstr(cmd, "GET_PARAMS") != NULL)
    {
        char buffer[128];
        sprintf(buffer, "PARAMS|IN_PLACE=%d|GROUND=%d|FULL=%d|STUCK=%d|SPEED=%d\r\n",
                threshold_in_place, threshold_ground, threshold_full, threshold_stuck, motor_speed);
        WiFi_SendData((uint8_t*)buffer, strlen(buffer));
        printf("参数已发送\r\n");
        return;
    }
    
    // 手动下钻
    if(strstr(cmd, "CMD_DOWN") != NULL)
    {
        manual_control = 1;
        manual_cmd = 1;
        printf("手动下钻模式\r\n");
        WiFi_SendData((uint8_t*)"OK|MANUAL_DOWN\r\n", 18);
        return;
    }
    
    // 手动上提
    if(strstr(cmd, "CMD_UP") != NULL)
    {
        manual_control = 1;
        manual_cmd = 2;
        printf("手动上提模式\r\n");
        WiFi_SendData((uint8_t*)"OK|MANUAL_UP\r\n", 16);
        return;
    }
    
    // 急停
    if(strstr(cmd, "CMD_STOP") != NULL)
    {
        manual_control = 1;
        manual_cmd = 3;
        printf("急停！\r\n");
        WiFi_SendData((uint8_t*)"OK|EMERGENCY_STOP\r\n", 21);
        return;
    }
    
    // 复位（返回自动模式）
    if(strstr(cmd, "CMD_RESET") != NULL)
    {
        manual_control = 0;
        manual_cmd = 0;
        motor_status = MODE_IDLE;
        drill_mode = MODE_IDLE;
        is_reversing = 0;
        is_in_place = 0;
        HAL_GPIO_WritePin(MOTOR_PORT, MOTOR_STP_PIN, GPIO_PIN_RESET);
        printf("复位到自动模式\r\n");
        WiFi_SendData((uint8_t*)"OK|RESET_TO_AUTO\r\n", 20);
        return;
    }
    
    // 未知指令
    WiFi_SendData((uint8_t*)"ERROR|UNKNOWN_CMD\r\n", 20);
    printf("未知指令: %s\r\n", cmd);
}

// ==================== WiFi模块相关函数 ====================

void WiFi_GPIO_Init(void)
{
    GPIO_InitTypeDef GPIO_InitStruct = {0};
    __HAL_RCC_GPIOB_CLK_ENABLE();
    
    GPIO_InitStruct.Pin = WIFI_RST_PIN;
    GPIO_InitStruct.Mode = GPIO_MODE_OUTPUT_PP;
    GPIO_InitStruct.Pull = GPIO_NOPULL;
    GPIO_InitStruct.Speed = GPIO_SPEED_FREQ_LOW;
    HAL_GPIO_Init(WIFI_RST_PORT, &GPIO_InitStruct);
    
    GPIO_InitStruct.Pin = WIFI_IO_PIN;
    GPIO_InitStruct.Mode = GPIO_MODE_INPUT;
    GPIO_InitStruct.Pull = GPIO_NOPULL;
    HAL_GPIO_Init(WIFI_RST_PORT, &GPIO_InitStruct);
    
    printf("WiFi引脚初始化完成\r\n");
}

void WiFi_Reset(void)
{
    HAL_GPIO_WritePin(WIFI_RST_PORT, WIFI_RST_PIN, GPIO_PIN_RESET);
    HAL_Delay(100);
    HAL_GPIO_WritePin(WIFI_RST_PORT, WIFI_RST_PIN, GPIO_PIN_SET);
    HAL_Delay(2000);
    printf("WiFi模块已复位\r\n");
}

uint8_t WiFi_SendAT(const char* cmd, const char* expected, uint32_t timeout)
{
    uint8_t buffer[128];
    uint32_t start = HAL_GetTick();
    uint16_t index = 0;
    
    HAL_UART_Transmit(WIFI_UART_HANDLE, (uint8_t*)cmd, strlen(cmd), 100);
    HAL_UART_Transmit(WIFI_UART_HANDLE, (uint8_t*)"\r\n", 2, 100);
    
    while(HAL_GetTick() - start < timeout)
    {
        if(HAL_UART_Receive(WIFI_UART_HANDLE, &buffer[index], 1, 50) == HAL_OK)
        {
            if(index < sizeof(buffer)-1)
            {
                index++;
                buffer[index] = 0;
                if(strstr((char*)buffer, expected) != NULL)
                {
                    return 1;
                }
            }
        }
    }
    return 0;
}

void WiFi_Connect(void)
{
    char cmd[128];
    
    printf("\r\n========== WiFi配置开始 ==========\r\n");
    
    HAL_UART_Transmit(WIFI_UART_HANDLE, (uint8_t*)"+++", 3, 100);
    HAL_Delay(500);
    
    printf("测试AT指令...\r\n");
    if(!WiFi_SendAT("AT", "OK", 2000))
    {
        printf("WiFi模块无响应\r\n");
        wifi_connected = 0;
        return;
    }
    printf("✓ AT指令正常\r\n");
    HAL_Delay(500);
    
    printf("设置STA模式...\r\n");
    WiFi_SendAT("AT+CWMODE=1", "OK", 2000);
    HAL_Delay(500);
    
    printf("连接WiFi: %s...\r\n", WIFI_SSID);
    sprintf(cmd, "AT+CWJAP=\"%s\",\"%s\"", WIFI_SSID, WIFI_PASSWORD);
    if(!WiFi_SendAT(cmd, "OK", 10000))
    {
        printf("✗ WiFi连接失败\r\n");
        wifi_connected = 0;
        return;
    }
    printf("✓ WiFi连接成功\r\n");
    HAL_Delay(2000);
    
    printf("连接TCP服务器 %s:%s...\r\n", SERVER_IP, SERVER_PORT);
    sprintf(cmd, "AT+CIPSTART=\"TCP\",\"%s\",%s", SERVER_IP, SERVER_PORT);
    if(!WiFi_SendAT(cmd, "CONNECT", 5000))
    {
        printf("✗ TCP连接失败\r\n");
        wifi_connected = 0;
        return;
    }
    printf("✓ TCP连接成功\r\n");
    HAL_Delay(500);
    
    printf("开启透传模式...\r\n");
    WiFi_SendAT("AT+CIPMODE=1", "OK", 2000);
    HAL_Delay(500);
    
    printf("进入透传模式...\r\n");
    WiFi_SendAT("AT+CIPSEND", ">", 2000);
    printf("✓ WiFi透传模式已开启\r\n");
    printf("====================================\r\n\r\n");
    
    wifi_connected = 1;
}

void WiFi_SendData(uint8_t* data, uint16_t len)
{
    if(wifi_connected)
    {
        HAL_UART_Transmit(WIFI_UART_HANDLE, data, len, 100);
    }
}

void WiFi_SendStatus(uint16_t dist, uint8_t mode, uint8_t in_place, uint8_t reversing, 
                      uint16_t avg, uint16_t diff)
{
    char buffer[256];
    char *mode_str = "";
    char *status_str = "";
    
    switch(mode)
    {
        case MODE_IDLE:   mode_str = "IDLE"; break;
        case MODE_DOWN:   mode_str = "DOWN"; break;
        case MODE_UP:     mode_str = "UP"; break;
        case MODE_PAUSE:  mode_str = "PAUSE"; break;
        default:          mode_str = "UNKNOWN"; break;
    }
    
    if(in_place == 1)
        status_str = "IN_PLACE";
    else if(reversing == 1)
        status_str = "REVERSING";
    else if(mode == MODE_DOWN)
        status_str = "DRILLING";
    else if(mode == MODE_IDLE)
        status_str = "WAITING";
    else if(mode == MODE_PAUSE)
        status_str = "PAUSING";
    else
        status_str = "NORMAL";
    
    sprintf(buffer, "DATA|%d|%d|%s|%s|%d|%d|%d|%d|%d|%d|%d\r\n",
            (int)(HAL_GetTick()/1000), dist, mode_str, status_str, 
            in_place, reversing, avg, diff,
            threshold_in_place, threshold_ground, motor_speed);
    
    WiFi_SendData((uint8_t*)buffer, strlen(buffer));
}
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

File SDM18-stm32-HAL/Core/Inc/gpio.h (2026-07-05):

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
/* Define to prevent recursive inclusion -------------------------------------*/
#ifndef __GPIO_H__
#define __GPIO_H__

#ifdef __cplusplus
extern "C" {
#endif

/* Includes ------------------------------------------------------------------*/
#include "main.h"

/* USER CODE BEGIN Includes */
/* 用户包含文件区域 */
/* USER CODE END Includes */

/* USER CODE BEGIN Private defines */
/* 私有定义区域 - 引脚定义 */

// LED引脚定义（根据您的实际电路修改）
#define LED_Pin                         GPIO_PIN_13      // LED连接的引脚号
#define LED_GPIO_Port                   GPIOC            // LED连接的端口

// 步进电机控制引脚定义（新增）
#define STEPPER_EN_PIN                   GPIO_PIN_5       // PA5 - 使能引脚(EN)
#define STEPPER_STEP_PIN                 GPIO_PIN_6       // PA6 - 脉冲引脚(STP)
#define STEPPER_DIR_PIN                   GPIO_PIN_7       // PA7 - 方向引脚(DIR)
#define STEPPER_GPIO_PORT                GPIOA            // 步进电机使用的GPIO端口

// 为了方便使用，也可以定义组合
#define STEPPER_ALL_PINS                 (GPIO_PIN_5 | GPIO_PIN_6 | GPIO_PIN_7)  // 所有步进电机引脚

// 方向定义（可选，方便记忆）
#define STEPPER_DIR_CW                    GPIO_PIN_SET     // 顺时针方向
#define STEPPER_DIR_CCW                   GPIO_PIN_RESET   // 逆时针方向

// 使能电平定义（根据您的驱动器调整）
#define STEPPER_ENABLE_LEVEL              GPIO_PIN_RESET   // 使能电平（低电平有效）
#define STEPPER_DISABLE_LEVEL              GPIO_PIN_SET     // 禁用电平

/* USER CODE END Private defines */

void MX_GPIO_Init(void);

/* USER CODE BEGIN Prototypes */
/* 用户原型声明区域 */

// 这里可以添加一些便捷的宏定义或内联函数
// 例如：快速设置方向
#define STEPPER_SetDir_CW()     HAL_GPIO_WritePin(STEPPER_GPIO_PORT, STEPPER_DIR_PIN, GPIO_PIN_SET)
#define STEPPER_SetDir_CCW()    HAL_GPIO_WritePin(STEPPER_GPIO_PORT, STEPPER_DIR_PIN, GPIO_PIN_RESET)

// 快速使能/禁用电机
#define STEPPER_Enable()        HAL_GPIO_WritePin(STEPPER_GPIO_PORT, STEPPER_EN_PIN, STEPPER_ENABLE_LEVEL)
#define STEPPER_Disable()       HAL_GPIO_WritePin(STEPPER_GPIO_PORT, STEPPER_EN_PIN, STEPPER_DISABLE_LEVEL)

// 发送单个脉冲
#define STEPPER_Pulse_High()     HAL_GPIO_WritePin(STEPPER_GPIO_PORT, STEPPER_STEP_PIN, GPIO_PIN_SET)
#define STEPPER_Pulse_Low()      HAL_GPIO_WritePin(STEPPER_GPIO_PORT, STEPPER_STEP_PIN, GPIO_PIN_RESET)

/* USER CODE END Prototypes */

#ifdef __cplusplus
}
#endif
#endif /*__ GPIO_H__ */

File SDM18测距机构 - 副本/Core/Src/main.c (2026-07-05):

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
/* Includes ------------------------------------------------------------------*/
#include "main.h"
#include "usart.h"
#include "gpio.h"

/* USER CODE BEGIN Includes */
#include <stdbool.h>
#include <stdio.h>
#include <string.h>
/* USER CODE END Includes */

/* USER CODE BEGIN PD */
// 电机引脚定义
#define MOTOR_EN_PIN   GPIO_PIN_5      // 使能引脚
#define MOTOR_STP_PIN  GPIO_PIN_6      // 脉冲引脚
#define MOTOR_DIR_PIN  GPIO_PIN_7      // 方向引脚
#define MOTOR_PORT     GPIOA

// 钻具工作模式
#define MODE_IDLE       0    // 空闲
#define MODE_DOWN       1    // 正转下钻
#define MODE_UP         2    // 反转上提
#define MODE_PAUSE      3    // 暂停
#define MODE_WAIT       4    // 到位等待（判断卡芯/满芯）

// 距离阈值定义（单位：mm）
#define THRESHOLD_GROUND    800     // 地面上阈值（内管在顶部）
#define THRESHOLD_IN_PLACE  400     // 内管到位阈值（到此停止）
#define THRESHOLD_FULL      100     // 满芯阈值（小于100mm为满）
#define THRESHOLD_STUCK     10      // 卡芯判断差值（10mm以内为卡）

// 数组大小定义
#define DIST_ARRAY_SIZE     10      // 10个相邻测距的数组

// 时间定义（单位：ms）
#define MEASURE_INTERVAL    100     // 100ms测一次距离
#define PAUSE_TIME          3000    // 暂停3秒
#define PULSE_SPEED         1       // 1ms脉冲
/* USER CODE END PD */

/* USER CODE BEGIN PV */
// 电机控制变量
__IO int32_t pulse_count = 0;           // 脉冲计数
__IO uint8_t motor_status = MODE_IDLE;   // 电机当前状态
__IO uint32_t last_pulse_tick = 0;       // 上次脉冲时间

// 钻具控制变量
__IO uint8_t drill_mode = MODE_IDLE;     // 钻具工作模式
__IO uint32_t pause_start_time = 0;      // 暂停开始时间
__IO uint8_t pause_trigger_reason = 0;   // 暂停原因：1-卡芯 2-满芯

// 重要：标记当前是否在反转上提阶段
__IO uint8_t is_reversing = 0;           // 0-不是反转 1-正在反转上提

// 到位标记：表示已经到达400mm，开始卡芯/满芯判断
__IO uint8_t is_in_place = 0;            // 0-未到位 1-已到位

// 测距数组（用于卡芯和满芯判断）
__IO uint16_t dist_array[DIST_ARRAY_SIZE] = {0};  // 存储10个距离值
__IO uint8_t dist_array_index = 0;                 // 数组当前索引
__IO uint8_t dist_array_full = 0;                   // 数组是否已填满

// 传感器距离（从sdm18.c获取）
extern uint16_t gSDM18_Distance;
/* USER CODE END PV */

void SystemClock_Config(void);
/* USER CODE BEGIN PFP */
// 函数声明
void Motor_GPIO_Init(void);
void Motor_Set_Direction(uint8_t dir);
void Motor_Generate_Pulse(void);
void Drill_Control(uint16_t dist);
void Update_Distance_Array(uint16_t dist);
uint8_t Check_Stuck(void);
uint8_t Check_Full(void);
void Print_Status(uint16_t dist);
/* USER CODE END PFP */

/**
  * @brief  The application entry point.
  * @retval int
  */
int main(void)
{
  HAL_Init();
  SystemClock_Config();
  MX_GPIO_Init();
  MX_USART1_UART_Init();
  MX_USART2_UART_Init();
  
  /* USER CODE BEGIN 2 */
  BSP_init();  // 传感器初始化
  
  // 电机GPIO初始化
  Motor_GPIO_Init();
  
  // 清空距离数组
  memset((void*)dist_array, 0, sizeof(dist_array));
  
  printf("\r\n====================================\r\n");
  printf("新型钻具机构控制系统启动\r\n");
  printf("阈值设置：到位=%dmm(停止) 满芯=<%dmm 卡芯差值<%dmm\r\n", 
         THRESHOLD_IN_PLACE, THRESHOLD_FULL, THRESHOLD_STUCK);
  printf("地面阈值：%dmm(反转停止)\r\n", THRESHOLD_GROUND);
  printf("测距间隔：%dms\r\n", MEASURE_INTERVAL);
  printf("====================================\r\n\r\n");
  /* USER CODE END 2 */

  /* Infinite loop */
  /* USER CODE BEGIN WHILE */
  while (1)
  {
    BSP_Loop();  // 处理传感器数据（会更新gSDM18_Distance）
    
    // 产生电机脉冲
    Motor_Generate_Pulse();
    
    // 每100ms执行一次控制逻辑
    static uint32_t last_control = 0;
    if(HAL_GetTick() - last_control >= MEASURE_INTERVAL)
    {
        last_control = HAL_GetTick();
        
        // 获取当前距离值
        uint16_t current_dist = gSDM18_Distance;
        
        // 更新距离数组（用于卡芯和满芯判断）
        Update_Distance_Array(current_dist);
        
        // 执行钻具控制逻辑
        Drill_Control(current_dist);
        
        // 串口打印状态
        Print_Status(current_dist);
    }
    
    /* USER CODE END WHILE */
    /* USER CODE BEGIN 3 */
  }
  /* USER CODE END 3 */
}

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
/* USER CODE BEGIN 4 */

/**
  * @brief 电机GPIO初始化
  */
void Motor_GPIO_Init(void)
{
    __HAL_RCC_GPIOA_CLK_ENABLE();
    
    GPIO_InitTypeDef GPIO_InitStruct = {0};
    GPIO_InitStruct.Pin = MOTOR_EN_PIN | MOTOR_STP_PIN | MOTOR_DIR_PIN;
    GPIO_InitStruct.Mode = GPIO_MODE_OUTPUT_PP;
    GPIO_InitStruct.Pull = GPIO_NOPULL;
    GPIO_InitStruct.Speed = GPIO_SPEED_FREQ_LOW;
    HAL_GPIO_Init(MOTOR_PORT, &GPIO_InitStruct);
    
    // 初始状态：使能有效，脉冲低，方向默认
    HAL_GPIO_WritePin(MOTOR_PORT, MOTOR_EN_PIN, GPIO_PIN_SET);   // 使能
    HAL_GPIO_WritePin(MOTOR_PORT, MOTOR_STP_PIN, GPIO_PIN_RESET); // 脉冲低
    HAL_GPIO_WritePin(MOTOR_PORT, MOTOR_DIR_PIN, GPIO_PIN_RESET); // 方向默认
}

/**
  * @brief 设置电机方向
  * @param dir: MODE_DOWN-下钻(正转)  MODE_UP-上提(反转)
  */
void Motor_Set_Direction(uint8_t dir)
{
    if(dir == MODE_DOWN)
    {
        HAL_GPIO_WritePin(MOTOR_PORT, MOTOR_DIR_PIN, GPIO_PIN_SET);   // 正转下钻
    }
    else if(dir == MODE_UP)
    {
        HAL_GPIO_WritePin(MOTOR_PORT, MOTOR_DIR_PIN, GPIO_PIN_RESET); // 反转上提
    }
}

/**
  * @brief 产生电机脉冲
  */
void Motor_Generate_Pulse(void)
{
    // 只有下钻或上提模式才发脉冲
    if(motor_status != MODE_DOWN && motor_status != MODE_UP)
        return;
    
    // 1ms产生一个脉冲
    if(HAL_GetTick() - last_pulse_tick >= 1)
    {
        last_pulse_tick = HAL_GetTick();
        HAL_GPIO_TogglePin(MOTOR_PORT, MOTOR_STP_PIN);
        pulse_count++;
    }
}

/**
  * @brief 更新距离数组（环形缓冲区）
  * @param dist: 当前距离值
  */
void Update_Distance_Array(uint16_t dist)
{
    // 将新距离存入数组当前位置
    dist_array[dist_array_index] = dist;
    
    // 更新索引（循环0-9）
    dist_array_index++;
    if(dist_array_index >= DIST_ARRAY_SIZE)
    {
        dist_array_index = 0;
        dist_array_full = 1;  // 标记数组已填满一次
    }
}

/**
  * @brief 检查是否卡芯
  * @retval 1-卡芯  0-正常
  */
uint8_t Check_Stuck(void)
{
    // 如果数组还没填满，无法判断
    if(!dist_array_full)
        return 0;
    
    // 找出数组中的最大值和最小值
    uint16_t max_dist = 0;
    uint16_t min_dist = 65535;
    
    for(int i = 0; i < DIST_ARRAY_SIZE; i++)
    {
        if(dist_array[i] > max_dist)
            max_dist = dist_array[i];
        if(dist_array[i] < min_dist)
            min_dist = dist_array[i];
    }
    
    // 计算差值
    uint16_t diff = max_dist - min_dist;
    
    // 如果差值小于阈值，说明距离变化很小 → 可能卡芯
    if(diff < THRESHOLD_STUCK)
    {
        return 1;
    }
    
    return 0;
}

/**
  * @brief 检查是否满芯
  * @retval 1-满芯  0-未满
  */
uint8_t Check_Full(void)
{
    // 如果数组还没填满，无法判断
    if(!dist_array_full)
        return 0;
    
    // 检查是否所有距离都小于满芯阈值
    for(int i = 0; i < DIST_ARRAY_SIZE; i++)
    {
        if(dist_array[i] >= THRESHOLD_FULL)
            return 0;  // 有一个大于等于阈值就不算满
    }
    
    return 1;
}
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

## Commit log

2026-10-09 Publish both final STM32 firmware variants with bilingual documentation
    Curate wifi-once and wifi-retry as the latest research source snapshot.
    Retain original control logic and required Keil/CubeMX/HAL/CMSIS sources.
    Replace four local network macros with an ignored configuration include.
    Add MIT/third-party notices, protocol, validation and versioned citation.
    Keep previous development uploads in Git history as authorized by the owner;
    do not rewrite history, rename the repository, or force-push.
    [28smd18.SLDASM, 65外管.SLDPRT, 80外管.SLDPRT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]
2026-10-10 Restore original project versions and publish thesis engineering drawings
    Preserve all 24 original directories and both final firmware variants.
    Add unchanged original drawings, file checksums and bilingual navigation.
    Keep the fixed v1.0.0 tag and release assets unchanged.
    [28smd18.SLDASM, 65内管.SLDDRW, 65外管.SLDPRT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]

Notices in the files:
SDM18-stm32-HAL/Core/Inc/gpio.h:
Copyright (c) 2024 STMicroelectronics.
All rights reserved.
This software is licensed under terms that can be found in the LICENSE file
